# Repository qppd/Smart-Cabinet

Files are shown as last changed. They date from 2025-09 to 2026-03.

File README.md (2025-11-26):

<div align="center">

# Smart Cabinet System






**An advanced IoT-enabled secure storage solution with fingerprint authentication, automated mechanisms, and intelligent monitoring.**

*Engineered by [QPPD](https://github.com/qppd) for smart access control and automated storage management.*

</div>

---

## 🎉 Project Status: COMPLETE

**The Smart Cabinet System is now fully finished and operational!** ✅

All core features have been implemented, tested, and validated:
- ✅ **Fingerprint Authentication**: Reliable biometric access with proper ID management
- ✅ **Motor Control System**: Precise stepper motor operations with watchdog protection
- ✅ **ESP-NOW Communication**: Stable peer-to-peer communication between host and client
- ✅ **Safety Systems**: Emergency stops, limit switches, and fail-safe mechanisms
- ✅ **3D Mechanical Design**: Complete assembly with custom mounting brackets and enclosures
- ✅ **User Interface**: LCD display, buzzer feedback, and tactile controls
- ✅ **Testing Suite**: Comprehensive validation commands for all subsystems

The system is ready for production deployment and real-world use.

---

## Recent Changes (v3.0)

### December 2025 Update - PROJECT COMPLETE
- **Full System Completion**: All features implemented and tested successfully
- **3D Model Documentation**: Added full assembly visualizations and component details
- **Production Ready**: System validated for real-world deployment
- **Documentation Enhancement**: Comprehensive README with visual guides and setup instructions
- **Code Optimization**: Final fixes for motor control, fingerprint management, and safety systems

### November 2025 Update
- **Motor Direction Inversion**: Corrected cabinet operation - fingerprint authentication now opens door (CCW), test_motor_limit closes door (CW)
- **Enhanced Testing Suite**: Added comprehensive door testing commands with proper stop conditions
- **test_close_door**: New command to close door until limit switch is pressed (CW direction)
- **test_open_door**: New command to open door for exact CLIENT_DOOR_OPEN_STEPS (CCW direction)
- **Updated State Machine**: Fixed executeUnlock(), handleOpeningState(), and handleClosingState() for correct motor directions

### October 2025 Update
- ESP-NOW Communication - Replaced WebSocket with ESP-NOW for reliable host-client communication
- Fingerprint Enrollment System - One-button enrollment via tactile button on GPIO 23
- Fixed Authentication Flow - Resolved double-read issue for reliable fingerprint matching
- Improved LCD Display - Eliminated flickering with optimized refresh logic
- Enhanced Buzzer System - Non-blocking PWM-based buzzer with proper timing
- NTP Time Synchronization - Internet-based time display (GMT+8)
- Fingerprint Management - Delete fingerprints and empty database features
- WiFi Integration - Automatic WiFi connection for NTP synchronization
- TactileButton Class - Debounced button handler with press/hold detection
- ESP32 Core 3.1.2 Support - Updated ESP-NOW callbacks for latest Arduino core

---

## Table of Contents

- [Overview](#overview)
- [Key Features](#key-features)
- [System Architecture](#system-architecture)
- [Hardware Requirements](#hardware-requirements)
- [Wiring Diagram](#wiring-diagram)
- [Software Dependencies](#software-dependencies)
- [Installation & Setup](#installation--setup)
- [Configuration](#configuration)
- [Operation Guide](#operation-guide)
- [API & Communication](#api--communication)
- [Testing & Validation](#testing--validation)
- [Troubleshooting](#troubleshooting)
- [Project Structure](#project-structure)
- [Future Enhancements](#future-enhancements)
- [Contributing](#contributing)
- [Support & Contact](#support--contact)
- [License](#license)

---

## Overview

The **Smart Cabinet System** is a sophisticated IoT-enabled secure storage solution designed for environments requiring controlled access and intelligent automation. This dual-controller architecture provides robust security, and seamless user interaction through biometric authentication and automated mechanical operations.

### Project Goals
- **Security**: Multi-layered access control with biometric authentication
- **Automation**: Intelligent operation with minimal user intervention  
- **Safety**: Comprehensive emergency systems and fail-safes
- **Scalability**: Modular design for easy expansion and customization
- **Reliability**: Robust error handling and system recovery

---

## Key Features

### Advanced Security
- **Biometric Authentication**: AS608 fingerprint sensor with 50+ user capacity
- **One-Touch Enrollment**: Simple button-press enrollment system (GPIO 23)
- **Reliable Matching**: Fixed authentication flow for consistent fingerprint recognition
- **Multi-layer Locking**: Electronic solenoid + mechanical stepper motor locks
- **Access Logging**: Real-time authentication tracking and user management
- **Emergency Override**: Manual unlock procedures for critical situations

### Intelligent Automation
- **Smart Motion Detection**: PIR sensor with adaptive sensitivity
- **Auto-Close System**: Configurable timeout (default: 60 seconds)
- **State Management**: Advanced finite state machine for reliable operation

### Safety Systems
- **Emergency Stop**: Immediate motor shutdown via limit switches
- **Position Monitoring**: Reed switch for precise door state detection
- **Fail-Safe Design**: Secure lock state during power failures

### Connectivity
- **ESP-NOW Communication**: Ultra-low latency peer-to-peer communication between controllers
- **WiFi Integration**: Network connectivity for NTP time synchronization

### User Experience
- **Visual Feedback**: 20x4 I2C LCD with flicker-free status information
- **Audio Alerts**: Multi-tone buzzer notifications
- **LED Illumination**: Automatic interior lighting control
- **Time Display**: NTP-synchronized real-time clock with timezone support
- **Simple Enrollment**: One-button fingerprint registration process

---

## System Architecture

### Distributed Controller Design

```mermaid
graph TB
    subgraph "HOST CONTROLLER (Authentication & Logic)"
        A[ESP32 Host] --> B[Fingerprint Sensor AS608]
        A --> C[20x4 I2C LCD Display]
        A --> D[NTP Time Sync]
        A --> E[Buzzer Audio Feedback]
        A --> F[ESP-NOW Host]
        A --> G[Enrollment Button GPIO 23]
    end
    
    subgraph "CLIENT CONTROLLER (Physical Operations)"
        H[ESP32 Client] --> I[PIR Motion Sensor]
        H --> J[TB6600 Motor Driver 1<br/>Door Mechanism]
        H --> K[TB6600 Motor Driver 2<br/>Lock Mechanism]
        H --> L[4-Channel Relay Board]
        H --> M[Safety Switches]
        H --> N[Reed Switch]
        H --> O[ESP-NOW Client]
    end
    
    subgraph "Physical Hardware"
        P[NEMA 17 Stepper Motors]
        Q[Solenoid Lock]
        R[LED Strip Lighting]
        S[Limit Switches]
    end
    
    F <==>|ESP-NOW Protocol| O
    J --> P
    K --> P
    L --> Q
    L --> R
    M --> S
```

### Control Flow Architecture

```mermaid
stateDiagram-v2
    [*] --> LOCKED
    LOCKED --> AUTHENTICATING : User Present
    AUTHENTICATING --> OPENING : Valid Fingerprint
    AUTHENTICATING --> LOCKED : Invalid/Timeout
    OPENING --> OPEN : Door Fully Open
    OPEN --> CLOSING : Motion Timeout
    OPEN --> CLOSING : Manual Close
    CLOSING --> LOCKED : Door Secured
    
    OPENING --> ERROR : Motor Timeout
    CLOSING --> ERROR : Motor Timeout
    ERROR --> LOCKED : System Reset
```

---

## Hardware Requirements

### Microcontrollers
| Component | Specification | Quantity | Purpose |
|---|---|---|---|
| **ESP32 DevKit** | 240MHz, 4MB Flash, WiFi/BT | 2 | Host & Client Controllers |

### Sensors & Input Devices
| Component | Model/Type | Interface | Function |
|---|---|---|---|
| **Fingerprint Sensor** | AS608/R307 | UART (Serial2) | Biometric Authentication |
| **Enrollment Button** | Tactile Push Button | Digital GPIO 23 | Fingerprint Enrollment Trigger |
| **PIR Motion Sensor** | HC-SR501 | Digital GPIO | User Presence Detection |
| **Reed Switch** | Magnetic Contact | Digital GPIO | Door Position Sensing |
| **Limit Switches** | Mechanical NO/NC | Digital GPIO | Motor Safety Limits |

### Actuators & Motor Control
| Component | Specification | Quantity | Application |
|---|---|---|---|
| **Stepper Motors** | NEMA 17, 1.8°/step | 2 | Door & Lock Mechanisms |
| **TB6600 Drivers** | 4A, 9-42V Input | 2 | Stepper Motor Control |
| **Solenoid Lock** | 12V, Fail-Secure | 1 | Primary Locking Mechanism |
| **4-Channel Relay** | 5V Logic, 10A Contact | 1 | Power Switching Control |

### Display & Feedback
| Component | Specification | Interface | Purpose |
|---|---|---|---|
| **LCD Display** | 20x4 Character, I2C | I2C Bus | System Status & Messages |
| **Buzzer** | Piezo, 2-5V | PWM GPIO | Audio Feedback |
| **LED Strip** | 12V, Addressable | Relay Control | Interior Illumination |

### Power Requirements
| System Component | Voltage | Current | Notes |
|---|---|---|---|
| **ESP32 Controllers** | 5V | 500mA each | Via USB or external supply |
| **Logic Components** | 3.3V/5V | 200mA total | From ESP32 regulation |
| **Stepper Motors** | 12-24V | 2-4A peak | Separate high-power supply |
| **Solenoid & LEDs** | 12V | 1A continuous | Shared with motor supply |

---

### 3D Printed Enclosures

Custom-designed 3D printable components for professional installation and sensor protection.

#### Fingerprint Scanner Components
| Component | File Format | Purpose | Print Time | Material |
|---|---|---|---|---|
| **Scanner Case** | STL + G-code | AS608/R307 protective enclosure | 2-3 hours | PLA/PETG |
| **Mounting Bracket** | STL + G-code | Secure cabinet attachment | 1-2 hours | PLA/PETG |

**Features:**
- Snap-fit design for easy sensor installation
- Integrated wire management channels
- Professional appearance for user-facing installation
- Pre-sliced G-code available for Creality Ender 3 V3 SE

**Printing Specifications:**
- **Layer Height:** 0.2mm recommended
- **Infill Density:** 20-30% for optimal strength-to-weight ratio
- **Support Material:** Required for overhangs (auto-generated in slicer)
- **Nozzle Temperature:** PLA: 200-210°C, PETG: 230-250°C
- **Bed Temperature:** PLA: 60°C, PETG: 80°C

**Files Location:** All STL and G-code files available in [`model/`](https://github.com/qppd/Smart-Cabinet/tree/main/model) directory

---

### 3D Model Visualizations

Complete assembly views of the Smart Cabinet mechanical system showcasing all custom-designed components.

<div align="center">

#### Full Assembly View (Wireframe)
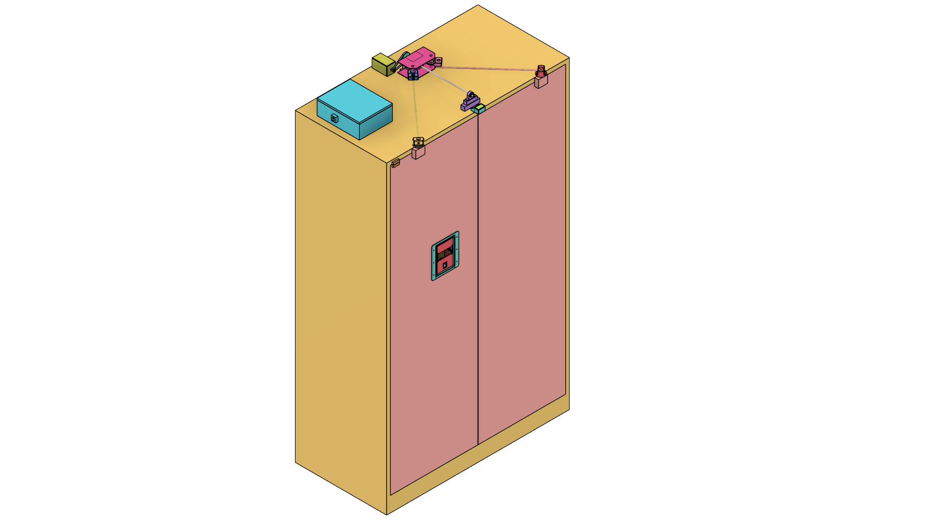
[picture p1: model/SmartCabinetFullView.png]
Smart Cabinet Full View

*Complete mechanical assembly showing internal component placement and motor mounting systems*

#### Full Assembly View (Rendered)
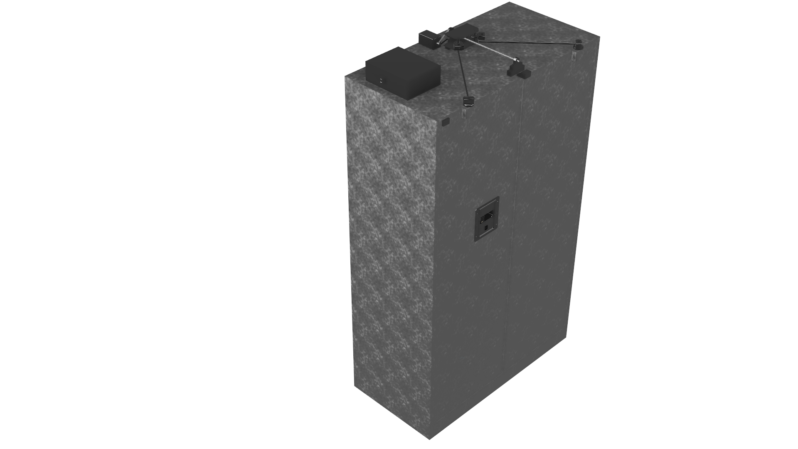
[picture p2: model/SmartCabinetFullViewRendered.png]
Smart Cabinet Rendered View

*Photorealistic render of the assembled Smart Cabinet with all mounting brackets and hardware*

</div>

**Assembly Components Include:**
- Stepper motor mounting brackets with integrated bearing supports
- Door puller mechanism with linear actuator mount
- Limit switch mounting system with protective covers
- Motion sensor bracket for optimal detection coverage
- Fingerprint scanner enclosure with mounting plate
- Cable management channels and wire routing guides

**Design Features:**
- Modular component system for easy maintenance and upgrades
- Integrated mounting points for all electronic components
- Optimized clearances for smooth mechanical operation
- Professional appearance with clean, modern aesthetics
- All components designed for standard FDM 3D printing

**Individual Component Views:** Detailed images of each mounting bracket and enclosure available in the [`model/`](https://github.com/qppd/Smart-Cabinet/tree/main/model) directory.

---

### Component Procurement Guide

#### **Microcontrollers & Development Boards**
| Component | Specifications | Supplier | Approximate Cost | Notes |
|---|---|---|---|---|
| **ESP32 DevKit V1** | ESP32-WROOM-32, 38-pin | Amazon, AliExpress | $8-15 | Ensure CH340 USB chip |
| **ESP32 DevKit V4** | ESP32-WROOM-32D, 38-pin | Espressif, DigiKey | $12-20 | Official version |

#### **Sensors & Input Devices**
| Component | Model | Specifications | Supplier | Cost |
|---|---|---|---|---|
| **Fingerprint Sensor** | AS608 / R307 | UART, 50 templates | Amazon, AliExpress | $15-25 |
| **PIR Motion Sensor** | HC-SR501 | 3-7m range, 3.3V logic | Amazon, SparkFun | $3-8 |
| **Reed Switch** | MC-38 | Magnetic, NO contact | Amazon, AliExpress | $2-5 |
| **Limit Switches** | KW12-3 | Microswitch, NO/NC | Amazon, McMaster | $3-8 each |
| **Tactile Button** | 12mm | 4-pin, momentary | Amazon, Adafruit | $1-3 |

#### **Motor Control Components**
| Component | Model | Specifications | Supplier | Cost |
|---|---|---|---|---|
| **NEMA 17 Motors** | 17HS4401 | 1.8°, 1.7A, 4-wire | Amazon, StepperOnline | $15-25 each |
| **TB6600 Drivers** | TB6600HG | 4A, 9-42V, 32μstepping | Amazon, AliExpress | $12-20 each |
| **4-Channel Relay** | SRD-05VDC-SL-C | 5V coil, 10A contact | Amazon, AliExpress | $8-15 |
| **Solenoid Lock** | 12V Electric Lock | Fail-secure, 12V DC | Amazon, Security stores | $20-40 |

#### **Display & Interface**
| Component | Model | Specifications | Supplier | Cost |
|---|---|---|---|---|
| **I2C LCD** | 2004A + I2C Module | 20x4, HD44780, 0x27 | Amazon, AliExpress | $8-15 |
| **DS1302 RTC** | DS1302 Module | Real-time clock, battery | Amazon, AliExpress | $3-8 |
| **Piezo Buzzer** | Active/Passive | 3-5V, PCB mount | Amazon, DigiKey | $2-5 |

#### **Power Supply Components**
| Component | Specifications | Supplier | Cost | Notes |
|---|---|---|---|---|
| **Switching PSU** | 12V 5A (60W) | Amazon, Mean Well | $15-30 | Choose reputable brand |
| **Buck Converter** | LM2596 12V→5V 3A | Amazon, AliExpress | $3-8 | Adjustable output |
| **Power Jack** | 5.5×2.1mm DC Jack | Amazon, DigiKey | $2-5 | Panel mount |

#### **Wiring & Connectors**
| Item | Specifications | Supplier | Cost | Quantity |
|---|---|---|---|---|
| **Hookup Wire** | 22AWG stranded | Amazon, McMaster | $10-20 | 10m spools |
| **Power Wire** | 16AWG stranded | Amazon, McMaster | $15-25 | 5m spool |
| **Dupont Connectors** | 2.54mm pitch | Amazon, AliExpress | $5-10 | 100pc kit |
| **Terminal Blocks** | 3.5mm pitch | Amazon, Phoenix | $10-20 | Various sizes |
| **Heat Shrink** | Assorted sizes | Amazon, 3M | $8-15 | Multi-size kit |

### Total Estimated Cost
| Category | Cost Range |
|---|---|
| **Controllers & Sensors** | $60-120 |
| **Motor System** | $80-150 |
| **Power & Wiring** | $40-80 |
| **Enclosure & Mechanical** | $50-150 |
| **Total Project Cost** | **$230-500** |

*Costs vary by supplier, quantity, and quality. Budget for 20% contingency.*

---

## Wiring Diagram

### System Wiring Overview

#### HOST Controller Wiring

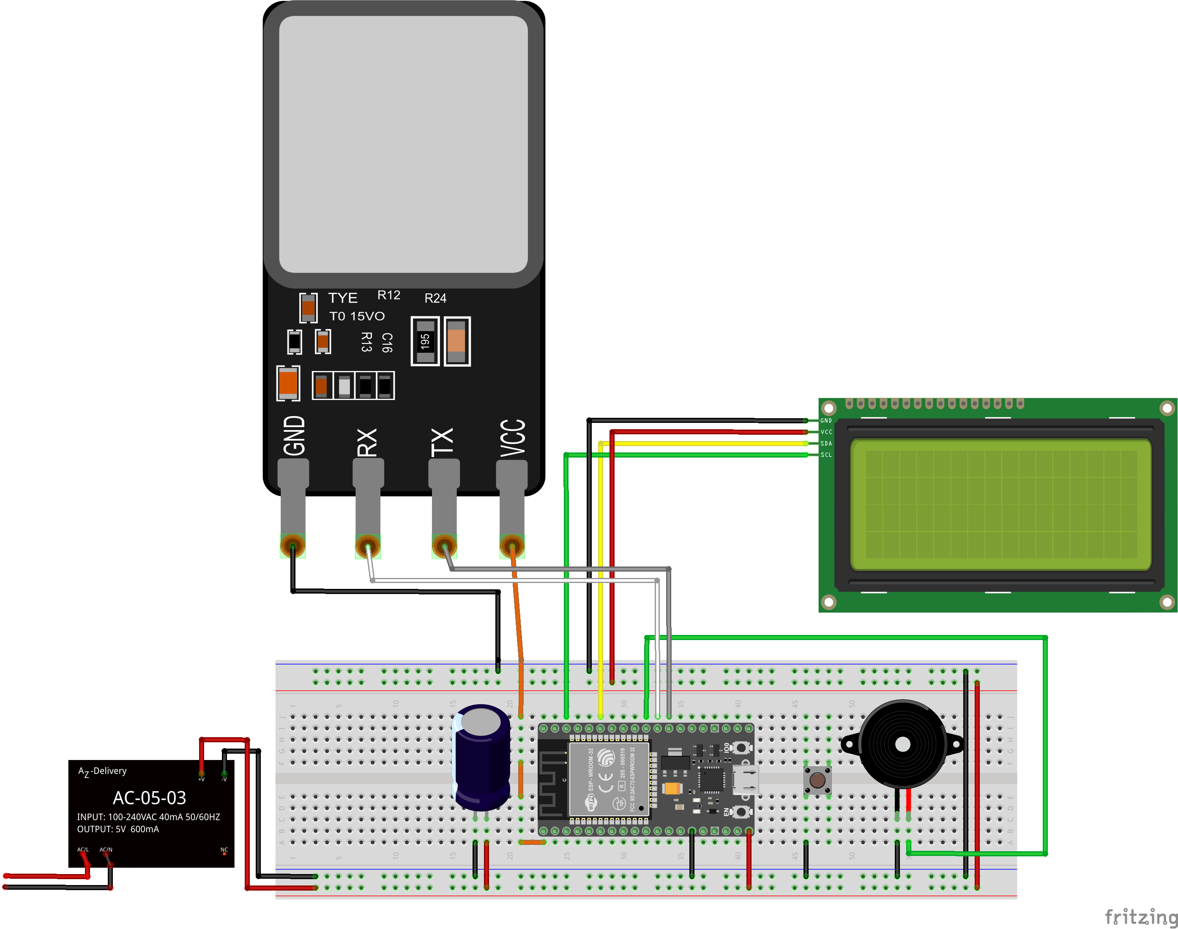
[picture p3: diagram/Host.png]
Smart Cabinet Host Wiring Diagram


*HOST controller wiring schematic showing authentication and user interface connections*

#### CLIENT Controller Wiring

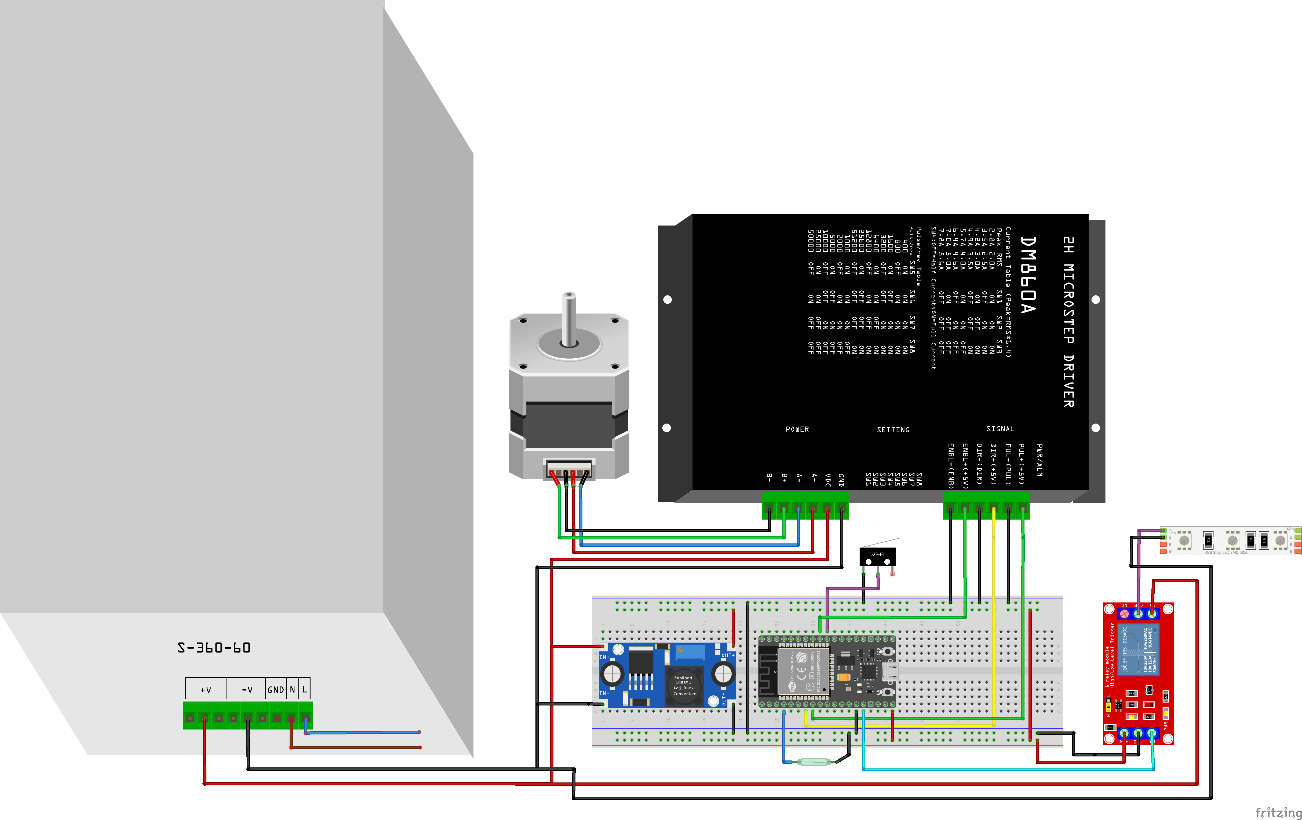
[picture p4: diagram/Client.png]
Smart Cabinet Client Wiring Diagram


*CLIENT controller wiring schematic showing motor control and safety system connections*

### Dual-Controller Architecture

The Smart Cabinet system uses a distributed controller architecture with two ESP32 microcontrollers:

- **HOST Controller (ESP32 #1)**: Handles authentication, user interface, and system coordination
- **CLIENT Controller (ESP32 #2)**: Manages mechanical operations, motor control, and safety systems

Communication between controllers uses **ESP-NOW protocol** for ultra-low latency and reliable peer-to-peer communication.

---

### HOST Controller Connections (ESP32 #1)

#### Display & User Interface
| Component | ESP32 Pin | Wire Color | Connection Details | Voltage |
|---|---|---|---|---|
| **20x4 I2C LCD** | SDA: 21 | Blue | I2C Data Line | 5V |
| | SCL: 22 | Yellow | I2C Clock Line | 5V |
| | VCC | Red | Power Supply | 5V |
| | GND | Black | Common Ground | GND |
| | **I2C Address: 0x27** | | *Use I2C scanner if different* | |

#### Authentication System
| Component | ESP32 Pin | Wire Color | Connection Details | Protocol |
|---|---|---|---|---|
| **AS608 Fingerprint Sensor** | TX2: 17 | Green | UART Transmit | Serial2 |
| | RX2: 16 | White | UART Receive | Serial2 |
| | VCC | Red | Power Supply | 3.3V |
| | GND | Black | Common Ground | GND |
| **Enrollment Button** | GPIO 23 | Orange | Digital Input | Pull-up |
| | GND | Black | Button Common | GND |

#### Real-Time Clock Module
| Component | ESP32 Pin | Wire Color | Connection Details | Interface |
|---|---|---|---|---|
| **DS1302 RTC** | CE: 0 | Purple | Chip Enable/Reset | Digital |
| | CLK: 19 | Gray | Clock Signal | Digital |
| | DAT: 18 | Brown | Data I/O | Digital |
| | VCC | Red | Power Supply | 5V |
| | GND | Black | Common Ground | GND |

#### Audio Feedback
| Component | ESP32 Pin | Wire Color | Connection Details | Control |
|---|---|---|---|---|
| **Piezo Buzzer** | GPIO 5 | Pink | PWM Signal | LEDC Ch.0 |
| | GND | Black | Common Ground | GND |

#### Power & Communication
| Connection | ESP32 Pin | Wire Color | Specification | Notes |
|---|---|---|---|---|
| **Power Input** | VIN | Red | 5V DC Input | From buck converter |
| | GND | Black | Common Ground | Shared with all components |
| **ESP-NOW** | Built-in WiFi | | 2.4GHz Radio | Peer-to-peer with CLIENT |

---

### CLIENT Controller Connections (ESP32 #2)

#### Motion Detection
| Component | ESP32 Pin | Wire Color | Connection Details | Type |
|---|---|---|---|---|
| **PIR Motion Sensor** | GPIO 34 | Orange | Digital Input | Input-only pin |
| | VCC | Red | Power Supply | 5V |
| | GND | Black | Common Ground | GND |

#### Motor Control System

**TB6600 Stepper Driver #1 (Door/Drawer Motor):**
| Function | ESP32 Pin | TB6600 Pin | Wire Color | Purpose |
|---|---|---|---|---|
| **Direction** | GPIO 2 | DIR+ | Blue | Rotation direction |
| **Step Pulse** | GPIO 4 | PUL+ | Green | Step commands |
| **Enable** | GPIO 15 | ENA+ | White | Driver enable (LOW=active) |
| **Common** | GND | DIR-, PUL-, ENA- | Black | Signal ground |

**TB6600 Stepper Driver #2 (Lock Mechanism Motor):**
| Function | ESP32 Pin | TB6600 Pin | Wire Color | Purpose |
|---|---|---|---|---|
| **Direction** | GPIO 32 | DIR+ | Yellow | Rotation direction |
| **Step Pulse** | GPIO 33 | PUL+ | Orange | Step commands |
| **Enable** | GPIO 5 | ENA+ | Purple | Driver enable (LOW=active) |
| **Common** | GND | DIR-, PUL-, ENA- | Black | Signal ground |

**TB6600 Power Connections:**
| Terminal | Connection | Wire Gauge | Voltage | Current |
|---|---|---|---|---|
| **VCC/VDD** | +12V Power | 16 AWG | 12V DC | 4A Max |
| **GND** | Power Ground | 16 AWG | GND | Return |
| **A+, A-** | Motor Phase A | 18 AWG | Motor | 2A |
| **B+, B-** | Motor Phase B | 18 AWG | Motor | 2A |

#### Relay Control System
| Relay | ESP32 Pin | Load Connection | Wire Color | Purpose | Max Load |
|---|---|---|---|---|---|
| **Relay 1** | GPIO 12 | Solenoid Lock | Red | Primary lock mechanism | 10A @ 250V |
| **Relay 2** | GPIO 13 | LED Strip | Blue | Interior illumination | 10A @ 250V |
| **Relay 3** | GPIO 14 | Auxiliary 1 | Green | Future expansion | 10A @ 250V |
| **Relay 4** | GPIO 27 | Auxiliary 2 | Yellow | Future expansion | 10A @ 250V |

**Relay Module Power:**
| Terminal | Connection | Wire Color | Voltage |
|---|---|---|---|
| **VCC** | +5V | Red | 5V DC |
| **GND** | Ground | Black | GND |
| **JD-VCC** | +5V | Red | Optocoupler power |

#### Safety & Sensors
| Component | ESP32 Pin | Wire Color | Connection Type | Function |
|---|---|---|---|---|
| **Limit Switch MIN** | GPIO 35 | Brown | NO Contact | Minimum position detect |
| **Limit Switch MAX** | GPIO 36 | Orange | NO Contact | Maximum position detect |
| **Reed Switch** | GPIO 39 | Purple | Magnetic Contact | Door closed detection |
| **Common Ground** | GND | Black | Switch Common | All sensor returns |

#### Power & Communication
| Connection | ESP32 Pin | Wire Color | Specification | Notes |
|---|---|---|---|---|
| **Power Input** | VIN | Red | 5V DC Input | From buck converter |
| | GND | Black | Common Ground | Shared with all components |
| **ESP-NOW** | Built-in WiFi | | 2.4GHz Radio | Peer-to-peer with HOST |

---

### Power Distribution System

```
 Main Power Supply (12V 5A Switching PSU)
├──  TB6600 Motor Driver #1 (12V 2A) ──→  NEMA 17 Door Motor
├──  TB6600 Motor Driver #2 (12V 2A) ──→  NEMA 17 Lock Motor  
├──  Solenoid Lock (12V 1A) ──→ via Relay 1
├──  LED Strip (12V 1A) ──→ via Relay 2
└──  Buck Converter (LM2596) (12V → 5V 3A)
    ├──  ESP32 Host Controller (5V 500mA)
    ├──  ESP32 Client Controller (5V 500mA)
    ├──  20x4 I2C LCD Display (5V 200mA)
    ├──  AS608 Fingerprint Sensor (3.3V 100mA)
    ├──  PIR Motion Sensor (5V 50mA)
    ├──  DS1302 RTC Module (5V 10mA)
    ├──  Piezo Buzzer (5V 20mA)
    ├──  4-Channel Relay Module (5V 150mA)
    └──  Safety Switches & Sensors (5V 50mA)
```

### Connector & Terminal Specifications

#### Recommended Connectors
| Connection Type | Connector | Wire Gauge | Rating |
|---|---|---|---|
| **Power (12V)** | Terminal Block | 14-16 AWG | 15A |
| **Motor Connections** | Terminal Block | 16-18 AWG | 5A |
| **Signal Wires** | Dupont Connectors | 22-24 AWG | 1A |
| **Sensor Cables** | JST Connectors | 24-26 AWG | 500mA |

#### Wire Color Standards
| Function | Color | Purpose |
|---|---|---|
| **Power (+)** | Red | Positive voltage |
| **Ground (-)** | Black | Ground/negative |
| **Data/Signal** | Various | Digital I/O |
| **I2C SDA** | Blue | I2C data |
| **I2C SCL** | Yellow | I2C clock |
| **UART TX** | Green | Serial transmit |
| **UART RX** | White | Serial receive |

### Assembly Notes

#### Critical Safety Requirements
1. **Isolation**: Keep high-voltage (12V motor) and low-voltage (5V logic) circuits separated
2. **Grounding**: Use common ground point to prevent ground loops
3. **Fusing**: Install appropriate fuses on 12V power lines
4. **Strain Relief**: Secure all cables to prevent disconnection during operation

#### Testing Checklist
- [ ] Verify all power supply voltages before connecting ESP32 controllers
- [ ] Test continuity of all signal connections
- [ ] Confirm proper motor driver configuration (current limiting)
- [ ] Validate safety switch operation (emergency stops)
- [ ] Check ESP-NOW communication range and reliability

### Advanced Wiring Considerations

#### Electromagnetic Interference (EMI) Mitigation

**Motor Noise Suppression:**
```
┌─ Stepper Motor Cable (Shielded)
├─ Ferrite Core (Split-bead, 10-30MHz)
├─ Twisted Pair Wiring (A+/A-, B+/B-)
└─ Shield Connection to Motor Frame Ground

TB6600 Layout:
- Separate analog/digital grounds
- Place 0.1μF ceramic caps near logic pins
- Use 1000μF electrolytic on motor supply
- Keep switching circuits away from ESP32
```

**Signal Integrity Protection:**
```
Critical Signals (I2C, UART, SPI):
├─ Use twisted pair or shielded cable <30cm
├─ Add series resistors (47Ω) for signal damping
├─ Ground shield at one end only (avoid ground loops)
└─ Route away from switching power circuits

Digital Input Protection:
├─ 10kΩ pull-up resistors on all inputs
├─ 100pF ceramic caps for debouncing
├─ TVS diodes for ESD protection (optional)
└─ Optical isolation for noisy environments
```

#### Professional Installation Practices

**Cable Management:**
- Use cable trays or conduit for organized routing
- Maintain 6" separation between power and signal cables
- Label all cables with wire markers or heat shrink labels
- Create service loops for future maintenance access

**Grounding Strategy:**
- Establish single-point ground (star configuration)
- Use heavy gauge wire (12-14 AWG) for ground bus
- Connect all metal enclosures to safety ground
- Install ground fault circuit breaker for AC power

**Environmental Considerations:**
- IP65 rated enclosures for humid environments
- Operating temperature: -10°C to +50°C
- Ventilation for heat dissipation from motor drivers
- Vibration dampening for stepper motor mounting

#### Safety & Code Compliance

**Electrical Safety:**
- Install 5A slow-blow fuse on 12V supply
- Use UL-listed power supplies and enclosures
- Implement emergency stop (E-stop) button
- Ground fault protection for wet locations

**Fire Safety:**
- Use flame-retardant cable jacket materials
- Install thermal protection on motor drivers
- Smoke detection in enclosed installations
- Regular inspection of electrical connections

#### Maintenance & Serviceability

**Test Points & Diagnostics:**
- Install LED indicators for power rails
- Add test points for critical signals
- Include voltage monitoring in software
- Document all modifications and settings

**Spare Parts & Backup:**
- Keep spare ESP32 controllers programmed
- Stock critical sensors (fingerprint, PIR)
- Backup configuration settings to SD card
- Create wiring diagram updates for changes**

### Installation Checklist

#### Pre-Installation Verification
```bash
□ All components tested individually
□ Power supply load tested at full current
□ Cable continuity verified with multimeter
□ Insulation resistance >1MΩ measured
□ Grounding system continuity confirmed
```

#### Installation Steps
```bash
□ Mount ESP32 controllers in protective enclosures
□ Install power distribution (fused and switched)
□ Route and secure all signal cables
□ Connect motor drivers and test without motors
□ Install and calibrate all sensors
□ Perform full system integration test
```

#### Commissioning Tests
```bash
□ Power-on sequence verification
□ ESP-NOW communication test
□ Motor movement and limit switch operation
□ Fingerprint enrollment and authentication
□ Emergency stop and safety system test
□ Long-term reliability test (24-48 hours)
```

---

## Software Dependencies

### Required Arduino Libraries

| Library | Version | Repository | Purpose |
|---|---|---|---|
| **LiquidCrystal_I2C** | ≥1.1.2 | [johnrickman/LiquidCrystal_I2C](https://github.com/johnrickman/LiquidCrystal_I2C) | I2C LCD Control |
| **Adafruit Fingerprint** | ≥2.1.0 | [adafruit/Adafruit-Fingerprint-Sensor-Library](https://github.com/adafruit/Adafruit-Fingerprint-Sensor-Library) | AS608 Communication |
| **RTClib** | ≥2.1.1 | [adafruit/RTClib](https://github.com/adafruit/RTClib) | DS1302 RTC Interface |
| **ArduinoWebsockets** | ≥0.5.3 | [gilmaimon/ArduinoWebsockets](https://github.com/gilmaimon/ArduinoWebsockets) | WebSocket Communication |
| **ArduinoJson** | ≥6.21.2 | [bblanchon/ArduinoJson](https://github.com/bblanchon/ArduinoJson) | JSON Message Processing |
| **WiFi** | Built-in | ESP32 Core | Network Connectivity |

### Development Environment

| Tool | Version | Download Link |
|---|---|---|
| **Arduino IDE** | ≥2.0.0 | [arduino.cc/software](https://www.arduino.cc/en/software) |
| **ESP32 Board Package** | ≥2.0.9 | [Espressif Arduino Core](https://github.com/espressif/arduino-esp32) |
| **VS Code** (Optional) | Latest | [PlatformIO Extension](https://platformio.org/platformio-ide) |

### Library Installation

**Via Arduino IDE Library Manager:**
```cpp
// Search and install each library:
// 1. LiquidCrystal_I2C by Frank de Brabander
// 2. Adafruit Fingerprint Sensor Library  
// 3. RTClib by Adafruit
// 4. ArduinoWebsockets by Gil Maimon
// 5. ArduinoJson by Benoit Blanchon
```

**Via PlatformIO (platformio.ini):**
```ini
[env:esp32dev]
platform = espressif32
board = esp32dev
framework = arduino
lib_deps = 
    johnrickman/LiquidCrystal_I2C@^1.1.2
    adafruit/Adafruit Fingerprint Sensor Library@^2.1.0
    adafruit/RTClib@^2.1.1
    gilmaimon/ArduinoWebsockets@^0.5.3
    bblanchon/ArduinoJson@^6.21.2
```

---

## Installation & Setup

### Hardware Assembly

#### 1. 3D Print Components (If Using Custom Enclosures)

**Print the Scanner Components:**
```bash
Option A: Use Pre-sliced G-code (Creality Ender 3 V3 SE)
  - Load CE3V3SE_Cabinet_Scanner_Case.gcode
  - Load CE3V3SE_Cabinet_Scanner_Case_Mount.gcode
  - Print with PLA or PETG filament

Option B: Slice STL Files (Any 3D Printer)
  - Import Cabinet_Scanner_Case.stl into your slicer
  - Import Cabinet_Scanner_Case_Mount.stl into your slicer
  - Configure settings: 0.2mm layer height, 20-30% infill
  - Generate and print G-code
```

**Assembly Instructions:**
- Allow printed parts to cool completely before handling
- Test-fit AS608/R307 sensor in scanner case before final assembly
- Clean any support material or stringing from prints
- Optional: Sand and paint for professional finish

#### 2. Mount Controllers and Sensors

1. **Install Fingerprint Scanner**: 
   - Insert AS608 sensor into printed scanner case
   - Secure with snap-fit mechanism or adhesive
   - Attach mounting bracket to cabinet using screws
   - Position at comfortable height for user access (typically 120-150cm)

2. **Mount ESP32 Controllers**: Secure both boards in protective enclosures or chassis

3. **Install Mechanical Components**:
   - Mount stepper motors for door and lock mechanisms
   - Position PIR motion sensor for optimal coverage
   - Install limit switches at mechanical endpoints

#### 3. Power and Wiring

1. **Connect Power**: Wire 12V supply to motor drivers and buck converter  
2. **Wire Sensors**: Follow pin configuration tables for all connections
3. **Cable Management**: Use wire channels in 3D printed parts for clean routing
4. **Test Connections**: Verify continuity and proper voltage levels

### Software Installation

**Clone Repository:**
```bash
git clone https://github.com/qppd/Smart-Cabinet.git
cd Smart-Cabinet
```

**Install Libraries:**
```bash
# If using Arduino IDE:
# 1. Open Library Manager (Ctrl+Shift+I)
# 2. Search and install required libraries listed above

# If using PlatformIO:
pio lib install
```

### Upload Firmware

**HOST Controller (Authentication Unit):**
```bash
# Navigate to host directory
cd source/host/SmartCabinet/

# Configure pins.h with your hardware setup
# Upload via Arduino IDE or PlatformIO to ESP32 #1
```

**CLIENT Controller (Mechanical Unit):**
```bash
# Navigate to client directory  
cd source/client/SmartCabinet/

# Configure client_pins.h with your hardware setup
# Upload via Arduino IDE or PlatformIO to ESP32 #2
```

### Initial System Verification

```bash
# Open Serial Monitor for both controllers
# Verify initialization messages:
# - WiFi connection established
# - All sensors responding
# - WebSocket connection active
# - Motor drivers enabled
```

---

## Configuration

### Network Configuration

**HOST Controller (`source/host/SmartCabinet/pins.h`):**
```cpp
// WiFi Network Settings
static const char* HOST_WIFI_SSID = "YourNetworkName";
static const char* HOST_WIFI_PASSWORD = "YourNetworkPassword";
static const uint16_t HOST_WEBSOCKET_PORT = 81;

// System Timing (milliseconds)
static const unsigned long HOST_DISPLAY_UPDATE_INTERVAL = 1000;
static const unsigned long HOST_FINGERPRINT_CHECK_INTERVAL = 500;
static const unsigned long HOST_STATUS_BROADCAST_INTERVAL = 5000;

// Security Settings
static const uint8_t MAX_FINGERPRINT_ATTEMPTS = 3;
static const unsigned long LOCKOUT_DURATION = 30000; // 30 seconds
static const uint8_t MAX_ENROLLED_FINGERPRINTS = 50;
```

**CLIENT Controller (`source/client/SmartCabinet/client_pins.h`):**
```cpp
// Network Connection
static const char* CLIENT_WIFI_SSID = "YourNetworkName";
static const char* CLIENT_WIFI_PASSWORD = "YourNetworkPassword";
static const char* CLIENT_WEBSOCKET_HOST = "192.168.1.100"; // HOST IP
static const uint16_t CLIENT_WEBSOCKET_PORT = 81;

// Motion & Timing Settings
static const unsigned long CLIENT_MOTION_TIMEOUT = 60000;      // 60 sec auto-close
static const unsigned long CLIENT_MOTOR_TIMEOUT = 30000;       // 30 sec motor limit
static const unsigned long CLIENT_WEBSOCKET_RETRY = 5000;      // 5 sec reconnect

// Motor Configuration (steps)
static const unsigned long CLIENT_DOOR_OPEN_STEPS = 2000;      // Full door travel
static const unsigned long CLIENT_DOOR_CLOSE_STEPS = 2000;
static const unsigned long CLIENT_LOCK_ENGAGE_STEPS = 400;     // Lock mechanism
static const unsigned long CLIENT_LOCK_RELEASE_STEPS = 400;

// Motor Speed (microseconds)
static const unsigned int CLIENT_MOTOR_PULSE_US = 100;         // Pulse width
static const unsigned int CLIENT_MOTOR_GAP_US = 800;           // Speed control
```

### Hardware Calibration

**Motor Step Calculation:**
```cpp
// Formula: Steps = (Degrees / Motor_Step_Angle) * Microstep_Setting
// Example: (90° / 1.8°) * 16 = 800 steps for 90° rotation

// Measure actual travel distances and adjust:
CLIENT_DOOR_OPEN_STEPS = measured_distance_mm * steps_per_mm;
CLIENT_LOCK_ENGAGE_STEPS = lock_rotation_degrees * steps_per_degree;
```

**Sensor Calibration:**
```cpp
// PIR Motion Sensor (adjust via potentiometers):
// - Sensitivity: Set to avoid false triggers
// - Time Delay: Minimum 3 seconds for stable operation

// Reed Switch: Test with magnet at various distances
// Optimal gap: 5-10mm for reliable switching
```

---

##  Operation Guide

### User Authentication Process

1. **Approach Cabinet**: Motion sensor detects user presence
2. **Fingerprint Scan**: Place enrolled finger on AS608 sensor
3. **Processing**: Host controller verifies biometric data (single-pass authentication)
4. **Access Grant**: Valid fingerprint triggers unlock sequence
5. **Automatic Opening**: Client executes door opening mechanism via ESP-NOW

**Authentication Flow:**
-  **Success**: LCD shows "Access Granted!" + ascending beeps + door unlocks
-  **Denied**: LCD shows "Access Denied!" + error beeps (3 short beeps)
- ⏸ **No Finger**: Silent operation (no spam messages)

### Fingerprint Enrollment

**Quick Enrollment Process:**

1. **Press Enrollment Button** (GPIO 23)
   - LCD displays "Starting Enroll..."
   - System auto-assigns next available ID

2. **First Scan**
   - LCD: "Place finger on sensor..."
   - Wait for confirmation beep
   - Hold finger steady on sensor

3. **Remove Finger**
   - LCD: "Remove finger"
   - Wait 2 seconds

4. **Second Scan**
   - LCD: "Place SAME finger again..."
   - Verify fingerprint matches
   
5. **Completion**
   - **Success**: "ENROLLMENT SUCCESS! User ID: X" + 3 ascending beeps
   - **Failed**: "ENROLLMENT FAILED!" + 3 error beeps
   - **Timeout**: 30 seconds if no finger detected

**Enrollment Specifications:**
- **Maximum Users**: 50 fingerprints supported
- **Enrollment Time**: ~15-30 seconds per user
- **Auto ID Assignment**: Based on template count
- **Database Full Check**: Automatic capacity monitoring
- **Template Storage**: Non-volatile sensor memory
- **Button Wiring**: GPIO 23 → Button → GND (internal pullup enabled)

### System Operation States

| State | LED Indicator | Buzzer | Description |
|---|---|---|---|
| **LOCKED** | Off | Silent | Secure state, waiting for user |
| **AUTHENTICATING** | Blinking | Short beep | Processing fingerprint |
| **OPENING** | Steady | Success tone | Door mechanism activating |
| **OPEN** | On | Silent | Cabinet accessible, monitoring motion |
| **CLOSING** | Blinking | Warning tone | Auto-close sequence active |
| **ERROR** | Fast blink | Alarm | System fault, manual intervention required |

###  **Automatic Features**

**Auto-Close System:**
- **Trigger**: 60 seconds of no motion detected
- **Warning**: LED flash and optional buzzer alert
- **Process**: Gradual door closing with safety checks
- **Override**: Motion detection cancels auto-close

**Emergency Stop:**
- **Activation**: Limit switch trigger or manual command
- **Response**: Immediate motor shutdown and error state
- **Recovery**: System reset required after clearing obstruction

---

## API & Communication

### ESP-NOW Protocol

**Communication Details:**
```cpp
// Protocol: ESP-NOW (Espressif's proprietary)
// Latency: <10ms typical
// Range: Up to 200m line-of-sight
// Pairing: MAC address-based peer connection
// Reliability: Automatic retransmission on failure
```

**Advantages over WebSocket:**
- ✅ Ultra-low latency communication
- ✅ No WiFi router dependency
- ✅ Lower power consumption
- ✅ Non-blocking operation
- ✅ Direct peer-to-peer connection

### Message Formats

**ESP-NOW Data Structure:**
```cpp
typedef struct {
    char command[32];      // Command type: "unlock", "authResult", "status"
    int userId;            // User ID from fingerprint
    bool success;          // Success/failure flag
    char data[64];         // Additional data
} ESPNowMessage;
```

**Authentication Event:**
```cpp
// Unlock Command (Host → Client)
{
  "command": "unlock",
  "userId": 12,
  "success": true,
  "data": ""
}

// Authentication Result (Host → Client)
{
  "command": "authResult",
  "userId": 5,
  "success": false,
  "data": "Access Denied"
}
}
```

**System Status:**
```json
{
  "type": "client_status",
  "timestamp": 1640995200000,
  "state": "OPEN",
  "door_open": true,
  "lock_engaged": false,
  "motion_detected": true,
  "reed_switch": false,
  "limit_switches": {
    "min": false,
    "max": false
  },
  "motors": {
    "door_running": false,
    "lock_running": false
  },
  "wifi_rssi": -45
}
```

**Command Messages:**
```json
{
  "type": "command",
  "command": "unlock_and_open",
  "user_id": 12,
  "timestamp": 1640995200000
}
```

### Emergency Commands

```json
{
  "type": "emergency",
  "command": "emergency_stop",
  "reason": "limit_switch_triggered",
  "timestamp": 1640995200000
}
```

### Diagnostic Data

```json
{
  "type": "diagnostic",
  "system_uptime": 3600000,
  "wifi_quality": 85,
  "fingerprint_database": {
    "enrolled_users": 25,
    "max_capacity": 50,
    "last_backup": 1640995200000
  },
  "motor_statistics": {
    "door_cycles": 1250,
    "lock_cycles": 1250,
    "total_runtime_hours": 12.5
  }
}
```

### Serial Command Testing Suite

The client controller includes a comprehensive serial command testing interface for validation and diagnostics. Connect via Serial Monitor at 115200 baud and use these commands:

**Available Test Commands:**
```bash
help                    # Show all available commands
test_relay              # Test relay 1 (solenoid) - ON/OFF sequence
test_motor1             # Test door motor - 2s CW, 2s CCW rotation
test_motor2             # Test lock motor - 2s CW, 2s CCW rotation
test_limit              # Test limit switches - press 3x to pass
test_motor_limit        # Motor runs until limit switch pressed (CW closing)
test_close_door         # Close door until limit switch is pressed (CW direction)
test_open_door          # Open door for CLIENT_DOOR_OPEN_STEPS (CCW direction)
test_motion             # Test PIR motion sensor - trigger to pass
test_reed               # Test reed switch - trigger to pass
```

**Test Command Details:**
- **`test_close_door`**: Runs door motor in CW direction until limit switch triggers, then stops
- **`test_open_door`**: Runs door motor in CCW direction for exactly 2000 steps (CLIENT_DOOR_OPEN_STEPS)
- **`test_motor_limit`**: Legacy command - runs motor until limit switch (CW closing direction)
- All motor tests include 30-second safety timeouts and detailed progress reporting

### Pre-Deployment Testing

**1. Hardware Verification:**
```bash
# Power Supply Test
- Verify 12V ±5% at motor drivers
- Confirm 5V ±5% at ESP32 controllers
- Check current consumption under load

# Sensor Calibration
- Test fingerprint sensor response time
- Verify motion sensor detection range
- Check reed switch activation distance
- Confirm limit switch trigger points
```

**2. Communication Testing:**
```bash
# Network Connectivity
- WiFi signal strength test (-50 dBm minimum)
- WebSocket connection stability (24-hour test)
- Message latency measurement (<100ms target)

# Inter-Controller Communication
- Command response verification
- Error handling validation  
- Reconnection testing
```

**3. Safety System Validation:**
```bash
# Emergency Stop Testing
- Limit switch activation response (<50ms)
- Manual emergency command (<100ms)
- Power failure recovery testing

# Mechanical Safety
- Door obstruction detection
- Motor stall protection
- Position verification accuracy
```

### Performance Benchmarks

| Metric | Target | Typical | Acceptance |
|---|---|---|---|
| **Authentication Time** | <2 seconds | 1.2 seconds | <3 seconds |
| **Door Open Time** | <5 seconds | 3.8 seconds | <8 seconds |
| **Door Close Time** | <5 seconds | 3.8 seconds | <8 seconds |
| **Motion Response** | <1 second | 0.3 seconds | <2 seconds |
| **WebSocket Latency** | <100ms | 45ms | <200ms |
| **Emergency Stop** | <50ms | 25ms | <100ms |

### Acceptance Testing Checklist

- [ ] **Power-on self-test passes**
- [ ] **All sensors respond correctly** 
- [ ] **Fingerprint enrollment successful**
- [ ] **Door mechanism operates smoothly**
- [ ] **Auto-close function works**
- [ ] **Emergency stop functions**
- [ ] **Network connectivity stable**
- [ ] **WebSocket communication active**
- [ ] **All safety systems operational**
- [ ] **Error recovery procedures work**

---

## Troubleshooting

### Wiring & Hardware Troubleshooting

#### Step-by-Step Connection Verification

**1. Power System Check:**
```bash
□ Main 12V supply: 11.5V - 12.5V (use multimeter)
□ Buck converter output: 4.9V - 5.1V  
□ ESP32 3.3V rail: 3.2V - 3.4V
□ All ground connections secure and continuous
□ No short circuits between power rails
```

**2. HOST Controller Verification:**
```bash
□ I2C LCD: SDA=21, SCL=22, Address 0x27
□ AS608 Sensor: TX2=17, RX2=16, 3.3V power
□ DS1302 RTC: CE=0, CLK=19, DAT=18, 5V power  
□ Buzzer: GPIO 5, active high
□ Enrollment Button: GPIO 23, pull-up enabled
```

**3. CLIENT Controller Verification:**  
```bash
□ PIR Sensor: GPIO 34 (input-only), 5V power
□ TB6600 #1: DIR=2, STEP=4, ENABLE=15
□ TB6600 #2: DIR=32, STEP=33, ENABLE=5
□ Relays: GPIO 12,13,14,27 (HIGH = active)
□ Limit Switches: GPIO 35,36 (pull-up, NO contacts)
□ Reed Switch: GPIO 39 (input-only, magnetic)
```

**4. Communication Test:**
```bash
Serial Monitor Commands:
HOST: "ESP-NOW: Host initialized"
CLIENT: "ESP-NOW: Client paired"
Both: "WiFi connected" (if using WiFi features)
```

#### Common Wiring Problems

**Issue: I2C LCD Not Working**
```bash
Symptoms: Blank display, garbled text, no backlight
Troubleshooting:
□ Verify I2C address with scanner: Wire.begin(); Wire.scan()
□ Check SDA/SCL connections (GPIO 21/22)
□ Test with 3.3V instead of 5V (some modules require 3.3V)
□ Ensure pull-up resistors present (usually on module)
Solutions:
- Try different I2C address (0x3F common alternative)
- Swap SDA/SCL if communication fails
- Add external 4.7kΩ pull-up resistors if needed
```

**Issue: Stepper Motors Erratic/Not Moving**
```bash
Symptoms: Jittery movement, wrong direction, no movement
Troubleshooting:
□ Check TB6600 DIP switch settings (current, decay mode)
□ Verify motor wiring: A+,A-,B+,B- to driver
□ Measure STEP signal: should show 3.3V pulses
□ Test ENABLE pin: LOW=enabled, HIGH=disabled
Solutions:
- Set TB6600 current to 1.5A (switches 5,6,7 = OFF,ON,OFF)
- Swap motor phase wires if direction incorrect
- Check step pulse timing (minimum 2.5μs pulse width)
```

**Issue: Fingerprint Sensor Communication Error**
```bash
Symptoms: "Sensor not found", incorrect readings
Troubleshooting:
□ Verify power: 3.3V (NOT 5V - can damage sensor)
□ Check UART wiring: ESP32 TX2→Sensor RX, ESP32 RX2→Sensor TX
□ Test baud rate: default 57600, try 9600 if issues
□ Ensure common ground connection
Solutions:
- Use voltage divider if accidentally connected to 5V
- Try hardware serial pins 1,3 instead of 16,17
- Reset sensor by power cycling
```

**Issue: ESP-NOW Communication Failed**
```bash
Symptoms: Controllers not communicating, timeout errors
Troubleshooting:
□ Both ESP32s on same WiFi channel
□ MAC addresses correctly configured
□ Distance <50 meters, clear line of sight
□ No interference from other 2.4GHz devices
Solutions:
- Scan and print MAC addresses: WiFi.macAddress()
- Force same WiFi channel with WiFi.channel()
- Use external antennas for better range
```

**Issue: Safety Switches Not Working**
```bash
Symptoms: Limit switches ignored, motors don't stop
Troubleshooting:
□ Check switch type: NO (Normally Open) required
□ Verify pull-up resistors enabled in code
□ Test switch continuity with multimeter
□ Ensure GPIO pins not shared with other functions
Solutions:
- Add external 10kΩ pull-up resistors
- Use interrupt-driven detection for faster response
- Test with LED to verify switch operation
```

#### Wiring Best Practices

**Signal Integrity:**
- Keep motor power wires away from signal wires (>2cm separation)
- Use twisted pairs for stepper motor connections
- Add ferrite cores on motor cables to reduce EMI
- Shield sensitive analog signals (if any added later)

**Power Distribution:**
- Use star grounding (single ground point) to prevent ground loops
- Add 100μF capacitors near each ESP32 for power stability  
- Install 1000μF capacitor on 12V rail for motor current spikes
- Use adequate wire gauge: 16AWG for 12V, 22AWG for 5V signals

**Connector Reliability:**
- Solder all permanent connections (avoid breadboards)
- Use screw terminals for high-current connections (>1A)
- Apply heat shrink tubing to all solder joints
- Label all wires with wire markers or heat-shrink labels

### Common Issues & Solutions

#### Power & Connectivity Issues

**Problem: ESP32 Controller Not Starting**
```bash
Symptoms: No serial output, LED indicators off
Diagnosis:
  - Check 5V power supply (measure with multimeter)
  - Verify USB cable connectivity
  - Test with known-good power source
Solutions:
  - Replace power supply if voltage <4.75V or >5.25V
  - Try different USB cable/port
  - Check for short circuits in wiring
```

**Problem: WiFi Connection Fails**
```bash
Symptoms: "WiFi connection failed" in serial monitor
Diagnosis:
  - Verify network credentials in configuration
  - Check WiFi signal strength (>-70 dBm)
  - Test with mobile hotspot
Solutions:
  - Update CLIENT_WIFI_SSID and CLIENT_WIFI_PASSWORD
  - Move device closer to router
  - Use 2.4GHz network (ESP32 limitation)
```

#### Motor & Mechanical Issues

**Problem: Stepper Motors Not Moving**
```bash
Symptoms: No motor movement, grinding sounds
Diagnosis:
  - Check TB6600 power supply (12-24V)
  - Verify STEP/DIR signal wiring
  - Test ENABLE pin state (LOW = enabled)
Solutions:
  - Measure motor supply voltage
  - Swap STEP/DIR pins if direction inverted
  - Check ENABLE pin connection (Pin 15 for Motor 1)
```

**Problem: Door Doesn't Close Properly**
```bash
Symptoms: Reed switch doesn't trigger, positioning errors
Diagnosis:
  - Check reed switch/magnet alignment
  - Verify step count accuracy
  - Test for mechanical obstructions
Solutions:
  - Adjust magnet position (5-10mm optimal gap)
  - Recalibrate CLIENT_DOOR_CLOSE_STEPS
  - Lubricate door mechanism
```

#### Sensor & Detection Issues

**Problem: Fingerprint Sensor Not Responding**
```bash
Symptoms: "Fingerprint sensor NOT found" error
Diagnosis:
  - Check Serial2 wiring (RX2:16, TX2:17)
  - Verify sensor power (3.3V or 5V depending on model)
  - Test with simple sensor library example
Solutions:
  - Swap RX/TX connections if needed
  - Check sensor power requirements
  - Replace sensor if hardware failure confirmed
```

**Problem: Motion Sensor False Triggers**
```bash
Symptoms: Excessive motion detection, auto-close not working
Diagnosis:
  - Check PIR sensor sensitivity setting
  - Verify mounting position and angle
  - Test ambient temperature variations
Solutions:
  - Adjust sensitivity potentiometer clockwise
  - Mount away from heat sources/air vents
  - Increase debounce time in software
```

#### Communication Issues

**Problem: WebSocket Connection Drops**
```bash
Symptoms: Intermittent connectivity, command delays
Diagnosis:
  - Monitor WiFi signal strength over time
  - Check router logs for disconnections
  - Verify WebSocket server on host
Solutions:
  - Implement longer reconnection timeout
  - Add WiFi signal quality monitoring
  - Use static IP assignment for stability
```

### Diagnostic Tools

#### Serial Monitor Commands
```cpp
// Add to main loop for debugging:
if (Serial.available()) {
  String command = Serial.readString();
  
  if (command == "test_motors") testMotorMovement();
  if (command == "check_sensors") printSensorStatus();
  if (command == "wifi_status") printWiFiDiagnostics();
  if (command == "reset_system") ESP.restart();
}
```

#### Hardware Testing Procedures

**Voltage Testing Points:**
```bash
# Power Supply Verification
Main Supply: 12V ±0.6V (11.4V - 12.6V acceptable)
ESP32 VIN: 5V ±0.25V (4.75V - 5.25V acceptable)  
ESP32 3.3V: 3.3V ±0.15V (3.15V - 3.45V acceptable)

# Signal Testing
STEP Pins: 0V/3.3V square wave during movement
DIR Pins: Steady 0V or 3.3V (direction dependent)
ENABLE Pins: 0V = enabled, 3.3V = disabled
```

**Sensor Verification:**
```bash
# Fingerprint Sensor (AS608)
Power: 3.3V or 5V (check sensor specification)
Communication: 57600 baud UART
Response: Sensor should respond to verifySensor() call

# Motion Sensor (PIR)  
Power: 5V (3.3V may work but reduced sensitivity)
Output: HIGH when motion detected, LOW when idle
Timing: 3-300 second trigger duration (adjustable)

# Reed Switch
Resistance: <1Ω closed, >10MΩ open
Activation: Magnet within 5-10mm distance
Wiring: Normally open contact to ESP32 input
```

### 📞 **Getting Additional Help**

If you encounter issues not covered here:

1. **Check Serial Output**: Enable debug mode and capture full startup sequence
2. **Document Error Messages**: Note exact error text and conditions when it occurs
3. **Test Individual Components**: Isolate issue to specific hardware/software component
4. **Create Minimal Test Case**: Simplify setup to reproduce issue consistently
5. **Contact Support**: Use information below with detailed problem description

---

## Maintenance

### Regular Checks
- **Weekly**: Verify door operation and sensor function
- **Monthly**: Check motor alignment and lubrication
- **Quarterly**: Inspect wiring connections and clean fingerprint sensor
- **Annually**: Replace mechanical wear components and re-enroll users

### Fingerprint Sensor Maintenance
- Keep sensor surface clean and dry
- Avoid excessive force during scanning
- Store templates periodically if sensor supports it
- Replace sensor if optical element degrades

### Motor and Mechanical Maintenance
- Check stepper motor connections and driver settings
- Verify limit switch operation and positioning
- Lubricate mechanical components as needed
- Test emergency stop functionality regularly

### Software Updates
- Monitor system logs for errors
- Update WiFi credentials if network changes
- Adjust timing parameters based on usage patterns
- Update motor parameters if hardware changes

---

## Fingerprint Management

### Enrolling New Users
1. Long-press the tactile button (5+ seconds) to enter enrollment mode
2. Follow LCD prompts to scan finger twice
3. Note the assigned ID number
4. Test authentication immediately

### Managing Stored Templates
- **View Count**: Use `count` command to see enrolled users
- **Delete User**: Use `delete <ID>` to remove specific fingerprint
- **Clear Database**: Use `empty` to remove all fingerprints
- **Check Capacity**: Sensor supports up to 50 templates

### Best Practices
- Enroll users with clean, dry fingers
- Avoid enrolling the same finger multiple times
- Regularly clean sensor surface
- Test authentication after enrollment
- Keep backup of enrolled user IDs

---

## Security Considerations

### Authentication Security
- **Biometric Data**: Fingerprints stored locally on sensor only
- **Template Protection**: No reverse-engineering of original fingerprint possible
- **Enrollment Control**: Restrict enrollment mode to authorized personnel
- **Access Logging**: Track authentication attempts with timestamps

### Physical Security
- **Tamper Protection**: Protect ESP32 and sensor from physical access
- **Cable Security**: Secure wiring to prevent disconnection
- **Environmental Protection**: Use enclosures for weather/water protection
- **Power Security**: Backup power for critical operations

### Network Security
- **ESP-NOW**: Direct peer-to-peer communication (no internet exposure)
- **WiFi Usage**: Only for NTP time sync (optional)
- **Local Network**: Keep controllers on secure local network
- **Firmware Security**: Keep ESP32 firmware updated

---

## Development and Customization

### Adding New Features
1. **Sensor Integration**: Create new sensor classes following existing patterns
2. **Motor Control**: Extend TB6600 class for additional motors
3. **Communication**: Add new ESP-NOW message types
4. **User Interface**: Modify LCD displays and buzzer patterns

### Code Structure Guidelines
- **Modular Design**: Keep functions focused and reusable
- **Error Handling**: Implement proper error checking and recovery
- **Documentation**: Comment code and update README for changes
- **Testing**: Add test commands for new features

### Hardware Modifications
- **Pin Changes**: Update pin definitions in respective header files
- **Component Swaps**: Modify initialization code for different components
- **Power Requirements**: Recalculate power needs for additions
- **Safety Systems**: Ensure emergency stops work with modifications

### Performance Tuning
- **Motor Speeds**: Adjust pulse timing for optimal performance
- **Sensor Sensitivity**: Calibrate PIR and limit switch parameters
- **Communication Timing**: Optimize ESP-NOW message intervals
- **Memory Usage**: Monitor ESP32 RAM and flash usage

---

## Project Structure

```
Smart-Cabinet/
├── 📁 source/
│   ├── 📁 host/SmartCabinet/              # HOST Controller (Authentication)
│   │   ├── SmartCabinet.ino               # Main host program
│   │   ├── pins.h                         # Host pin configuration
│   │   ├── I2CLcd.h/.cpp                  # LCD display driver
│   │   ├── FingerprintAS608.h/.cpp        # Biometric sensor interface
│   │   ├── DS1302Rtc.h/.cpp               # Real-time clock module
│   │   ├── Buzzer.h/.cpp                  # Audio feedback system
│   │   └── WebSocketServer.h/.cpp         # Network communication server
│   │
│   └── 📁 client/SmartCabinet/            # CLIENT Controller (Mechanical)
│       ├── SmartCabinet.ino               # Main client program  
│       ├── client_pins.h                  # Client pin configuration
│       ├── MotionSensor.h/.cpp            # PIR motion detection
│       ├── TB6600.h/.cpp                  # Stepper motor drivers
│       ├── Relay4.h/.cpp                  # Relay board control
│       ├── LimitSwitch.h/.cpp             # Safety switch handling
│       ├── ReedSwitch.h/.cpp              # Position sensing
│       ├── WebSocketClient.h/.cpp         # Network communication client
│       └── README.md                      # Client-specific documentation
│
├── 📁 diagram/                            # System Documentation
│   └── img20.jpg                          # Complete wiring diagram
│
├── 📁 model/                              # Design & 3D Models
│   ├── Cabinet_Actuator_Mount.png         # Actuator mount design preview
│   ├── Cabinet_Actuator_Mount.stl         # 3D printable actuator mounting bracket
│   ├── Cabinet_Door_Puller_Mount.png      # Door puller mount design preview
│   ├── Cabinet_Door_Puller_Mount.stl      # 3D printable door puller mounting bracket
│   ├── CE3V3SE_Cabinet_Door_Puller_Mount.gcode # Ready-to-print door puller mount (Creality Ender 3 V3 SE)
│   ├── Cabinet_Scanner_Case.png           # Scanner case design preview
│   ├── Cabinet_Scanner_Case.stl           # 3D printable fingerprint scanner enclosure
│   ├── Cabinet_Scanner_Case_Mount.png     # Scanner mount design preview
│   ├── Cabinet_Scanner_Case_Mount.stl     # 3D printable mounting bracket
│   ├── Cabinet_Scanner_Case_Cover.png     # Scanner case cover design preview
│   ├── Cabinet_Scanner_Case_Cover.stl     # 3D printable protective cover for scanner case
│   ├── CE3V3SE_Cabinet_Scanner_Case_Cover.gcode # Ready-to-print scanner case cover (Creality Ender 3 V3 SE)
│   ├── Cabinet_Stepper_Mount.gcode        # Ready-to-print stepper mount (Creality Ender 3 V3 SE)
│   ├── Cabinet_Stepper_Mount.stl          # 3D printable stepper motor mount
│   ├── CE3V3SE_Cabinet_Scanner_Case.gcode # Ready-to-print scanner case (Creality Ender 3 V3 SE)
│   ├── CE3V3SE_Cabinet_Scanner_Case_Mount.gcode # Ready-to-print mount (Creality Ender 3 V3 SE)
│   ├── CE3V3SE_Cabinet_Stepper_Mount_And_Bearing_Mount.gcode # Ready-to-print stepper and bearing mount (Creality Ender 3 V3 SE)
│   ├── Cabinet_Bearing_Mount.png          # Bearing mount design preview
│   ├── Cabinet_Bearing_Mount.stl          # 3D printable bearing mounting bracket
│   ├── CE3V3SE_Cabinet_Bearing_Mount.gcode # Ready-to-print bearing mount (Creality Ender 3 V3 SE)
│   ├── Cabinet_Limit_Switch_Mount.png     # Limit switch mount design preview
│   ├── Cabinet_Limit_Switch_Mount.stl     # 3D printable limit switch mounting bracket
│   ├── Cabinet_Limit_Switch_Mount_Cover.stl # Protective cover for limit switch mount
│   ├── CE3V3SE_Cabinet_Limit_Switch_Mount_Cover.gcode # Ready-to-print limit switch mount cover (Creality Ender 3 V3 SE)
│   ├── CE3V3SE_Cabinet_Limit_Switch_Mount.gcode # Ready-to-print limit switch mount (Creality Ender 3 V3 SE)
│   ├── Cabinet_Stick_Mount.png            # Stick mount design preview
│   ├── Cabinet_Stick_Mount.stl            # 3D printable stick mounting bracket
│   ├── CE3V3SE_Cabinet_Stick_Mount.gcode  # Ready-to-print stick mount (Creality Ender 3 V3 SE)
│   ├── Cabinet_Motion_Sensor_Mount.png    # Motion sensor mount design preview
│   ├── Cabinet_Motion_Sensor_Mount.stl    # 3D printable motion sensor mounting bracket
│   ├── CE3V3SE_Cabinet_Motion_Sensor_Mount.gcode # Ready-to-print motion sensor mount (Creality Ender 3 V3 SE)
│   ├── Cabinet_Motion_Sensor_Mount_Cover.stl # Protective cover for motion sensor mount
│   ├── SmartCabinet v0.png                # Initial concept design
│   ├── SmartCabinet v03.png               # Design iteration 3
│   └── SmartCabinet v4.png                # Final design version
├── README.md                              # Main project documentation
└── LICENSE                                # Project license file
```

### Architecture Overview

**HOST Controller Components:**
- `SmartCabinet.ino`: Main application logic and state management
- `I2CLcd.*`: 20x4 character display driver with I2C interface
- `FingerprintAS608.*`: Biometric sensor communication and authentication
- `DS1302Rtc.*`: Real-time clock for timestamp and scheduling
- `Buzzer.*`: PWM-driven audio feedback system  
- `WebSocketServer.*`: Network communication hub

**CLIENT Controller Components:**
- `SmartCabinet.ino`: Mechanical control and safety systems
- `MotionSensor.*`: PIR motion detection with debouncing
- `TB6600.*`: Stepper motor control with non-blocking operation
- `Relay4.*`: Multi-channel relay board for high-power switching
- `LimitSwitch.*`: Safety switch monitoring with interrupt handling
- `ReedSwitch.*`: Magnetic door position sensing
- `WebSocketClient.*`: Network communication with auto-reconnection

### Component Responsibilities

| Component | Primary Function | Secondary Function |
|---|---|---|
| **HOST Controller** | User authentication & interface | System coordination & logging |
| **CLIENT Controller** | Mechanical operations & safety | Environmental monitoring |
| **WebSocket Layer** | Real-time communication | Status reporting & diagnostics |
| **Safety Systems** | Emergency protection | Preventive maintenance alerts |
| **Motor Control** | Precise positioning | Load monitoring & protection |

---

## Future Enhancements

### Mobile Application Integration
- **Native App Development**: iOS/Android companion app for remote monitoring
- **Push Notifications**: Real-time alerts for security events and system status
- **Remote Control**: Emergency unlock and system management capabilities
- **User Management**: Fingerprint enrollment and access control via mobile interface

### Advanced AI Features
- **Behavioral Analytics**: Machine learning-based user pattern recognition
- **Predictive Maintenance**: AI-driven component health monitoring and failure prediction
- **Adaptive Security**: Dynamic access control based on time, location, and user behavior
- **Voice Control**: Integration with voice assistants for hands-free operation

### Enhanced Security Systems
- **Multi-Factor Authentication**: Combination of fingerprint, RFID, and PIN verification
- **Facial Recognition**: Computer vision-based secondary authentication
- **Tamper Detection**: Advanced intrusion detection with immediate alert systems
- **Encrypted Communication**: End-to-end encryption for all network communications

### IoT Ecosystem Integration
- **Home Automation**: Integration with existing smart home platforms (Home Assistant, OpenHAB)
- **Cloud Connectivity**: Secure cloud backup and remote access capabilities
- **API Gateway**: RESTful API for third-party system integration
- **Dashboard Interface**: Web-based management interface for system administration

### Performance Optimizations
- **Edge Computing**: Local AI processing for faster response times
- **Energy Management**: Advanced power saving modes and solar charging compatibility
- **Wireless Charging**: Contactless power delivery for maintenance-free operation
- **Mesh Networking**: Multi-device communication for scaled deployments

### User Experience Improvements
- **Customizable Interface**: Themeable LCD displays and configurable audio feedback
- **Multi-Language Support**: Internationalization for global deployment
- **Accessibility Features**: Voice prompts and tactile feedback for visually impaired users
- **Progressive Web App**: Browser-based configuration and monitoring interface

---

## Contributing

We welcome contributions from the community! Here's how you can help improve the Smart Cabinet System:

### Development Setup

1. **Fork the Repository**
   ```bash
   git clone https://github.com/qppd/Smart-Cabinet.git
   cd Smart-Cabinet
   git checkout -b feature/your-feature-name
   ```

2. **Development Environment**
   ```bash
   # Install required tools
   - Arduino IDE 2.0+ or PlatformIO
   - ESP32 Board Package
   - Required libraries (see dependencies section)
   ```

3. **Testing Setup**
   ```bash
   # Hardware requirements for testing
   - 2x ESP32 development boards
   - Breadboard and jumper wires for prototyping
   - Basic multimeter for voltage verification
   ```

### Contribution Guidelines

**Code Standards:**
- Follow Arduino/C++ naming conventions
- Add comprehensive comments for complex logic
- Include header documentation for all new functions
- Maintain consistent indentation (2 spaces)

**Documentation:**
- Update README.md for new features
- Add inline code comments for complex algorithms
- Include wiring diagrams for hardware changes
- Provide configuration examples

**Testing Requirements:**
- Test all new features on actual hardware
- Verify compatibility with existing functionality
- Include performance benchmarks for optimizations
- Document any breaking changes

### Priority Areas for Contribution

1. **Hardware Drivers**: New sensor and actuator support
2. **Communication Protocols**: Additional network interfaces
3. **Security Features**: Enhanced authentication methods
4. **User Interface**: Improved display and interaction systems
5. **Documentation**: Installation guides and troubleshooting
6. **Testing**: Automated testing frameworks and validation scripts

### Submission Process

1. **Create Feature Branch**: Use descriptive branch names
2. **Implement Changes**: Follow coding standards and add tests
3. **Update Documentation**: Include relevant documentation updates
4. **Submit Pull Request**: Provide detailed description of changes
5. **Review Process**: Collaborate with maintainers on feedback
6. **Merge Approval**: Final testing and integration

---

## Support & Contact

### Project Maintainer

**QPPD (Sajed Mendoza)**
- Portfolio: [sajed-mendoza.onrender.com](https://sajed-mendoza.onrender.com)
- GitHub: [@qppd](https://github.com/qppd)
- Email: quezon.province.pd@gmail.com

### Community & Social

- Facebook Developer Page: [QPPD Dev](https://facebook.com/qppd.dev)
- Organization: [Quezon Province Programmer/Developers](https://facebook.com/QUEZONPROVINCEDEVS)

### Technical Support

For Technical Issues:
1. **Search Existing Issues**: Check [GitHub Issues](https://github.com/qppd/Smart-Cabinet/issues)
2. **Create New Issue**: Use provided templates for bug reports or feature requests
3. **Include Information**: Hardware setup, error messages, and reproduction steps
4. **Response Time**: 24-48 hours for initial response

For General Questions:
- **Email Support**: Include "Smart Cabinet" in subject line
- **Community Forum**: Post in Facebook developer group
- **Live Chat**: Available on portfolio website during business hours

### Additional Resources

#### 3D Printable Components

All 3D models are available in the [model directory](https://github.com/qppd/Smart-Cabinet/tree/main/model) with ready-to-print files.

**Fingerprint Scanner Enclosure:**

<div align="center">
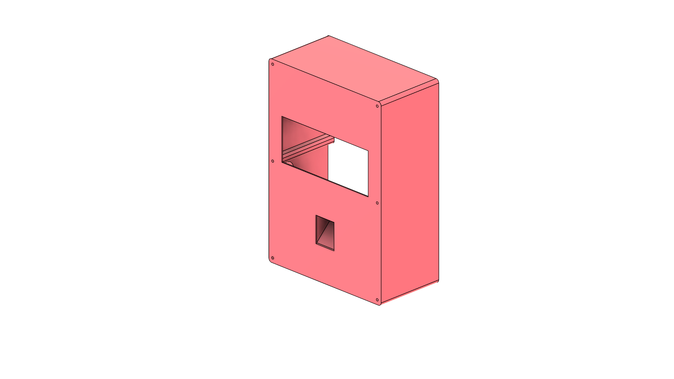
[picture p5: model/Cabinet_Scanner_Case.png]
Cabinet Scanner Case Preview
  
</div>

- **Files Available:**
  - `Cabinet_Scanner_Case.stl` - 3D model for any slicer software
  - `Cabinet_Scanner_Case.png` - Preview/reference image
  - `CE3V3SE_Cabinet_Scanner_Case.gcode` - Pre-sliced for Creality Ender 3 V3 SE
  
- **Purpose:** Protective enclosure for AS608/R307 fingerprint sensor
- **Features:**
  - Secure sensor mounting with snap-fit design
  - Wire management channels for clean installation
  - Professional appearance for cabinet integration
  - Compatible with standard fingerprint sensor modules

**Scanner Mounting Bracket:**

<div align="center">
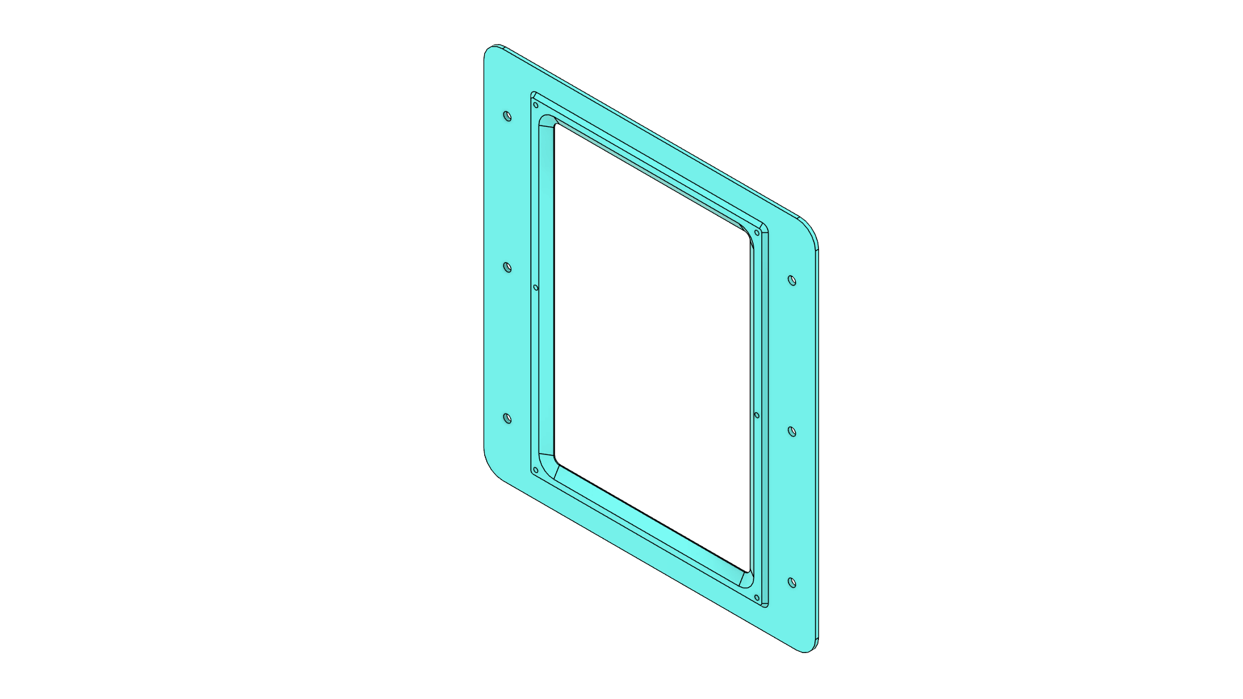
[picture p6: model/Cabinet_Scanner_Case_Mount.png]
Cabinet Scanner Case Mount Preview
  
</div>

- **Files Available:**
  - `Cabinet_Scanner_Case_Mount.stl` - 3D model for any slicer software
  - `Cabinet_Scanner_Case_Mount.png` - Preview/reference image
  - `CE3V3SE_Cabinet_Scanner_Case_Mount.gcode` - Pre-sliced for Creality Ender 3 V3 SE
  
- **Purpose:** Secure mounting bracket for scanner case attachment
- **Features:**
  - Adjustable positioning for optimal finger placement
  - Screw mounting points for permanent installation
  - Compatible with various cabinet materials
  - Lightweight yet sturdy construction

**Scanner Case Cover:**

<div align="center">
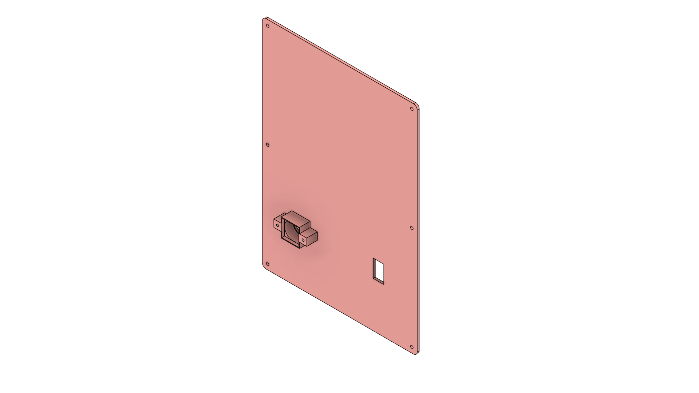
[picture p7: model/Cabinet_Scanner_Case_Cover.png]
Cabinet Scanner Case Cover Preview
  
</div>

- **Files Available:**
  - `Cabinet_Scanner_Case_Cover.stl` - 3D model for any slicer software
  - `Cabinet_Scanner_Case_Cover.png` - Preview/reference image
  - `CE3V3SE_Cabinet_Scanner_Case_Cover.gcode` - Pre-sliced for Creality Ender 3 V3 SE
  
- **Purpose:** Protective cover for the fingerprint scanner case
- **Features:**
  - Secure fit over the scanner enclosure
  - Environmental protection for sensitive components
  - Easy removal for maintenance access
  - Professional appearance integration

**Actuator Mount:**

<div align="center">
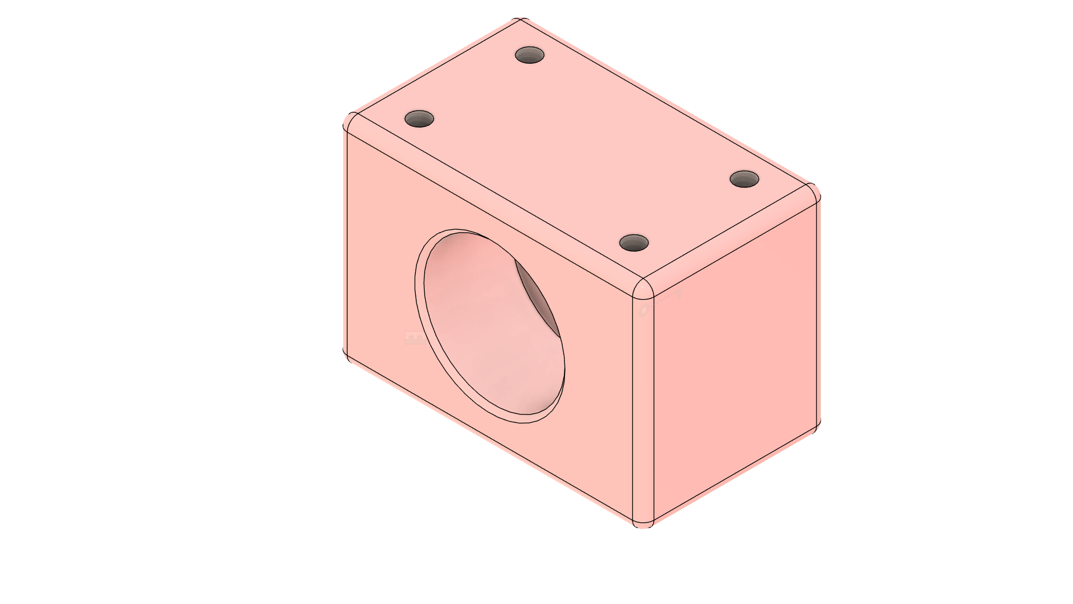
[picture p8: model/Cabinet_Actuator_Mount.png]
Cabinet Actuator Mount Preview
  
</div>

- **Files Available:**
  - `Cabinet_Actuator_Mount.stl` - 3D model for any slicer software
  - `Cabinet_Actuator_Mount.png` - Preview/reference image

- **Purpose:** Mounting bracket for cabinet actuator/linear actuator
- **Features:**
  - Robust design for secure actuator installation
  - Multiple mounting holes for flexible placement
  - Designed for easy integration with cabinet frame

**Door Puller Mount:**

<div align="center">
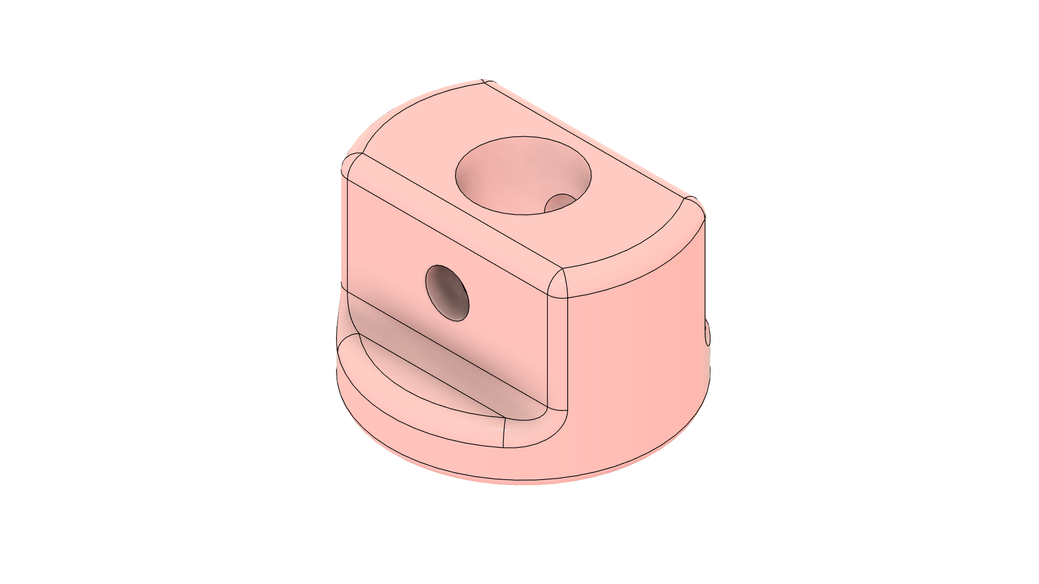
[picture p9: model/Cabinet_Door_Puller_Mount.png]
Cabinet Door Puller Mount Preview
  
</div>

- **Files Available:**
  - `Cabinet_Door_Puller_Mount.stl` - 3D model for any slicer software
  - `Cabinet_Door_Puller_Mount.png` - Preview/reference image
  - `CE3V3SE_Cabinet_Door_Puller_Mount.gcode` - Pre-sliced for Creality Ender 3 V3 SE

- **Purpose:** Mounting bracket for door pulling mechanism
- **Features:**
  - Designed for smooth door opening operation
  - Reinforced structure for reliable performance
  - Easy installation on cabinet frame
  - Compatible with various actuator types

**Stepper Motor Mount:**

- **Files Available:**
  - `Cabinet_Stepper_Mount.stl` - 3D model for any slicer software
  - `Cabinet_Stepper_Mount.gcode` - Pre-sliced for Creality Ender 3 V3 SE
  - `CE3V3SE_Cabinet_Stepper_Mount_And_Bearing_Mount.gcode` - Pre-sliced stepper and bearing mount (Creality Ender 3 V3 SE)

- **Purpose:** Mount for stepper motor used in cabinet locking or actuation
- **Features:**
  - Precise fit for NEMA stepper motors
  - Rigid structure for vibration reduction
  - Easy mounting to cabinet or enclosure
  - Includes integrated bearing mount for additional support

**Bearing Mount:**

<div align="center">
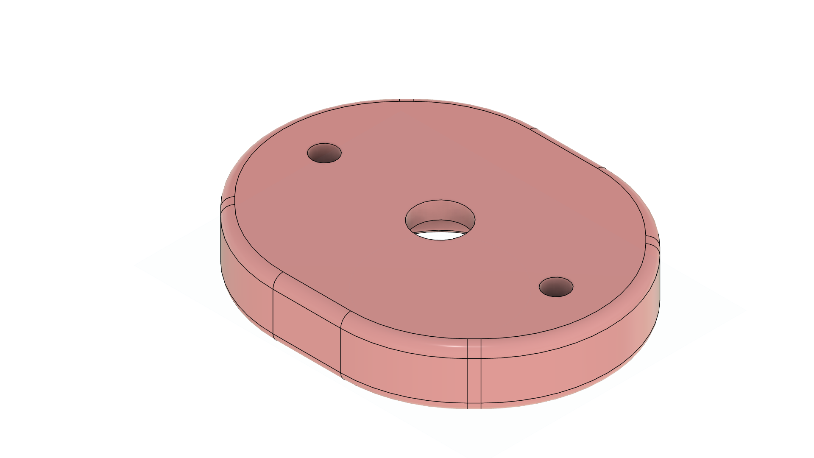
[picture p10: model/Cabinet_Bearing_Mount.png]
Cabinet Bearing Mount Preview
  
</div>

- **Files Available:**
  - `Cabinet_Bearing_Mount.stl` - 3D model for any slicer software
  - `Cabinet_Bearing_Mount.png` - Preview/reference image
  - `CE3V3SE_Cabinet_Bearing_Mount.gcode` - Pre-sliced for Creality Ender 3 V3 SE
  
- **Purpose:** Mounting bracket for bearings used in mechanical assemblies
- **Features:**
  - Secure bearing housing for smooth rotation
  - Compatible with standard bearing sizes
  - Easy integration with cabinet frame
  - Durable design for long-term reliability

**Limit Switch Mount:**

<div align="center">
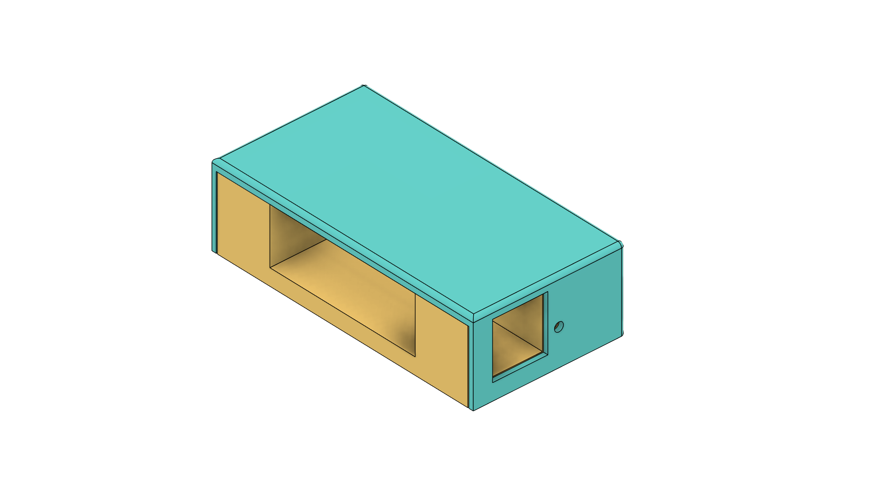
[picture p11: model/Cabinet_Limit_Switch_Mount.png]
Cabinet Limit Switch Mount Preview
  
</div>

- **Files Available:**
  - `Cabinet_Limit_Switch_Mount.stl` - 3D model for any slicer software
  - `Cabinet_Limit_Switch_Mount.png` - Preview/reference image
  - `CE3V3SE_Cabinet_Limit_Switch_Mount.gcode` - Pre-sliced for Creality Ender 3 V3 SE
  
- **Purpose:** Mounting bracket for limit switches in automated systems
- **Features:**
  - Precise positioning for accurate switch activation
  - Screw mounting for secure installation
  - Compatible with standard limit switch modules

**Limit Switch Mount Cover:**

- **Files Available:**
  - `Cabinet_Limit_Switch_Mount_Cover.stl` - Protective cover for limit switch mount
  - `CE3V3SE_Cabinet_Limit_Switch_Mount_Cover.gcode` - Pre-sliced for Creality Ender 3 V3 SE
  
- **Purpose:** Environmental protection for limit switch mounting assembly
- **Features:**
  - Secure fit over the limit switch mount
  - Protection from dust and moisture
  - Easy installation and removal
  - Maintains professional appearance

**Stick Mount:**

<div align="center">
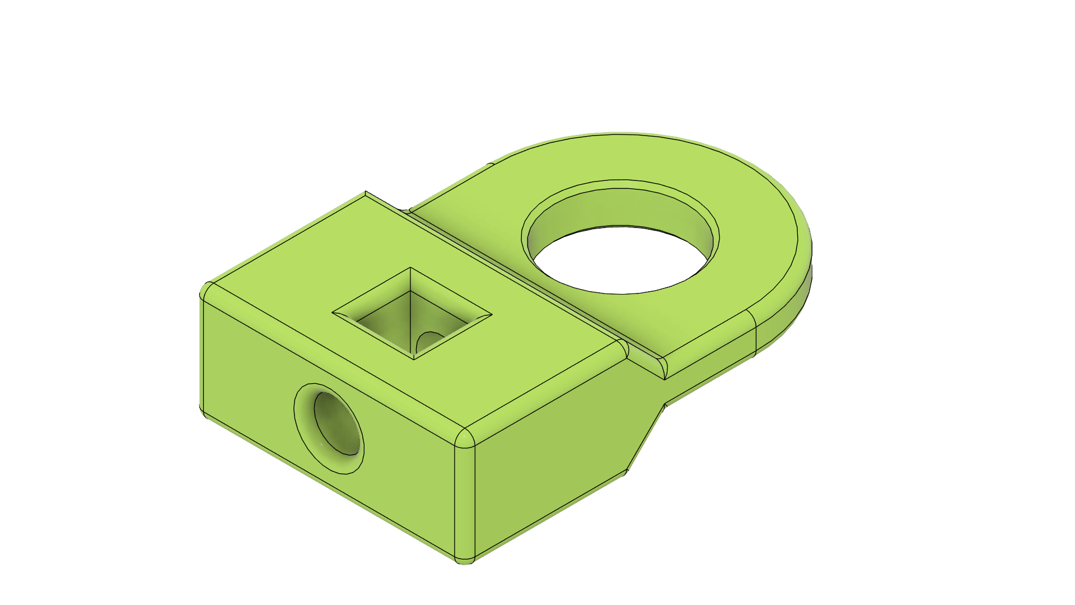
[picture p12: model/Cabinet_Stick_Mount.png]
Cabinet Stick Mount Preview
  
</div>

- **Files Available:**
  - `Cabinet_Stick_Mount.stl` - 3D model for any slicer software
  - `Cabinet_Stick_Mount.png` - Preview/reference image
  - `CE3V3SE_Cabinet_Stick_Mount.gcode` - Pre-sliced for Creality Ender 3 V3 SE
  
- **Purpose:** Mounting bracket for rods or sticks in mechanical linkages
- **Features:**
  - Adjustable mounting for flexible positioning
  - Robust construction for load-bearing applications
  - Easy assembly with standard fasteners
  - Designed for smooth operation in cabinet mechanisms

**Motion Sensor Mount:**

<div align="center">
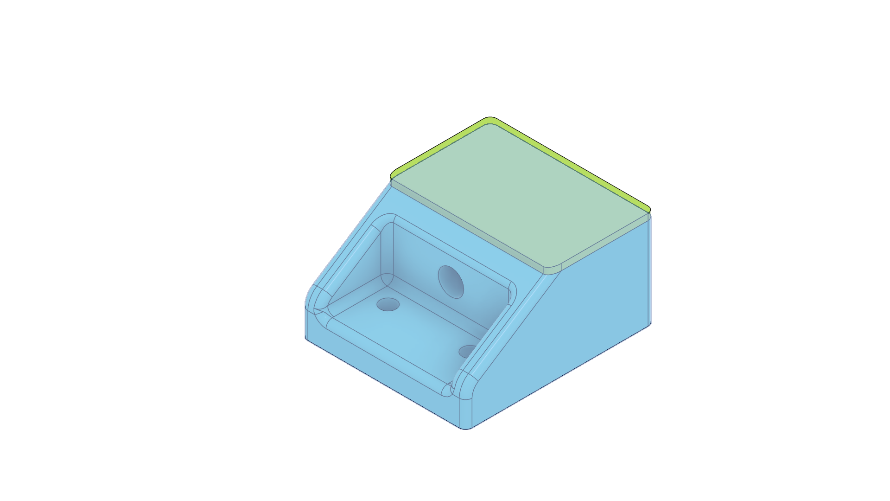
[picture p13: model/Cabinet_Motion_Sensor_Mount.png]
Cabinet Motion Sensor Mount Preview
  
</div>

- **Files Available:**
  - `Cabinet_Motion_Sensor_Mount.stl` - 3D model for any slicer software
  - `Cabinet_Motion_Sensor_Mount.png` - Preview/reference image
  - `CE3V3SE_Cabinet_Motion_Sensor_Mount.gcode` - Pre-sliced for Creality Ender 3 V3 SE
  
- **Purpose:** Mounting bracket for motion sensors in automated systems
- **Features:**
  - Optimal positioning for motion detection
  - Secure mounting for reliable operation
  - Compatible with standard motion sensor modules
  - Adjustable angle for customized coverage

**Motion Sensor Mount Cover:**

- **Files Available:**
  - `Cabinet_Motion_Sensor_Mount_Cover.stl` - Protective cover for motion sensor mount
  
- **Purpose:** Environmental protection for motion sensor mounting assembly
- **Features:**
  - Secure fit over the motion sensor mount
  - Protection from dust and environmental factors
  - Easy installation and removal
  - Maintains professional appearance

**Printing Recommendations:**
- **Material:** PLA or PETG recommended
- **Layer Height:** 0.2mm for optimal detail
- **Infill:** 20-30% for structural integrity
- **Supports:** May be required depending on orientation
- **Print Time:** Scanner case ~2-3 hours, mount ~1-2 hours

**Design Iterations:**
- `SmartCabinet v0.png` - Initial concept and planning
- `SmartCabinet v03.png` - Refined design with improvements
- `SmartCabinet v4.png` - Final production-ready design

## License

### MIT License

```
MIT License

Copyright (c) 2025 QPPD (Sajed Mendoza)

Permission is hereby granted, free of charge, to any person obtaining a copy
of this software and associated documentation files (the "Software"), to deal
in the Software without restriction, including without limitation the rights
to use, copy, modify, merge, publish, distribute, sublicense, and/or sell
copies of the Software, and to permit persons to whom the Software is
furnished to do so, subject to the following conditions:

The above copyright notice and this permission notice shall be included in all
copies or substantial portions of the Software.

THE SOFTWARE IS PROVIDED "AS IS", WITHOUT WARRANTY OF ANY KIND, EXPRESS OR
IMPLIED, INCLUDING BUT NOT LIMITED TO THE WARRANTIES OF MERCHANTABILITY,
FITNESS FOR A PARTICULAR PURPOSE AND NONINFRINGEMENT. IN NO EVENT SHALL THE
AUTHORS OR COPYRIGHT HOLDERS BE LIABLE FOR ANY CLAIM, DAMAGES OR OTHER
LIABILITY, WHETHER IN AN ACTION OF CONTRACT, TORT OR OTHERWISE, ARISING FROM,
OUT OF OR IN CONNECTION WITH THE SOFTWARE OR THE USE OR OTHER DEALINGS IN THE
SOFTWARE.
```

### License Terms

**Permissions:**
- Modification: Customize and extend functionality
- Distribution: Share modified versions with others
- Private Use: Use for personal projects and learning

**Conditions:**
- License Notice: Include original license in distributions
- Copyright Notice: Credit original author in derivative works

**Limitations:**
- Warranty: Software provided "as-is" without guarantees

### Educational Use

This project is specifically designed to be educational and learning-friendly:

- **Academic Projects**: Free use in schools, universities, and research institutions
- **STEM Education**: Encourage use in robotics and IoT curriculum  
- **Maker Spaces**: Support community workshops and maker initiatives
- **Open Source**: Promote collaborative development and knowledge sharing

### Commercial Licensing

For commercial deployments requiring additional support or custom licensing:

- **Volume Licensing**: Special terms for large-scale deployments
- **OEM Integration**: White-label licensing for product manufacturers

**Contact**: quezon.province.pd@gmail.com for commercial licensing inquiries.

---

<div align="center">

### Thank you for choosing Smart Cabinet System!

*Building the future of secure, intelligent storage solutions.*

**Star this repository if it helped you!**

</div>

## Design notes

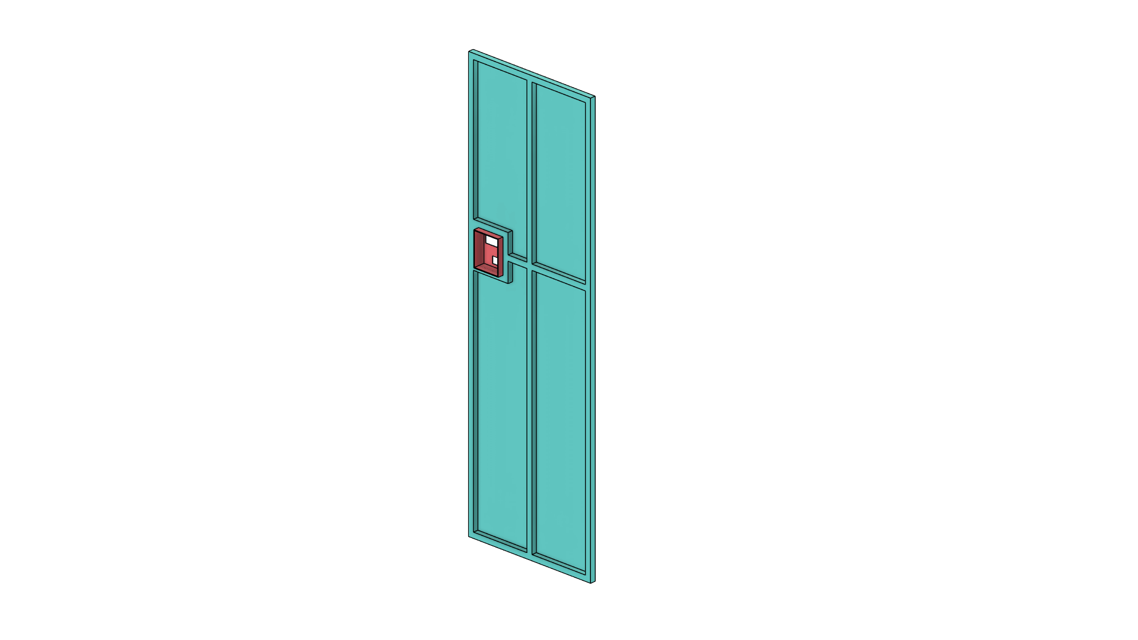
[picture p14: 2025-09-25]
model/SmartCabinet v0.png

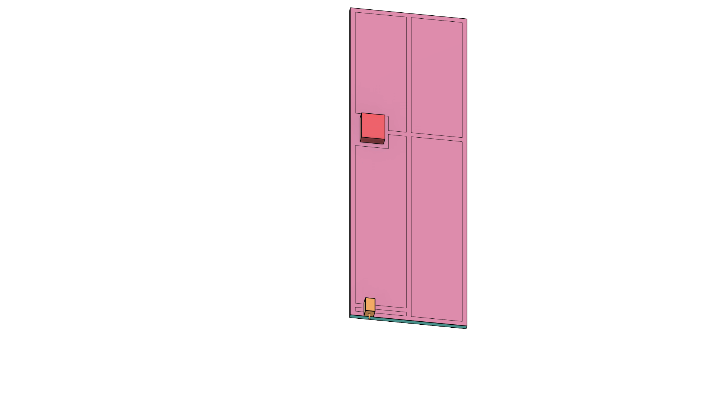
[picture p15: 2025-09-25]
model/SmartCabinet v4.png

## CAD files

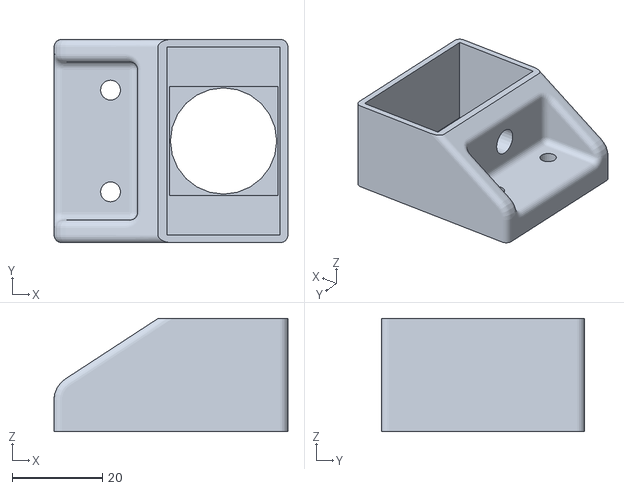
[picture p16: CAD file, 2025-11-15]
model/Cabinet_Motion_Sensor_Mount.stl
51.8 x 45.0 x 25.0

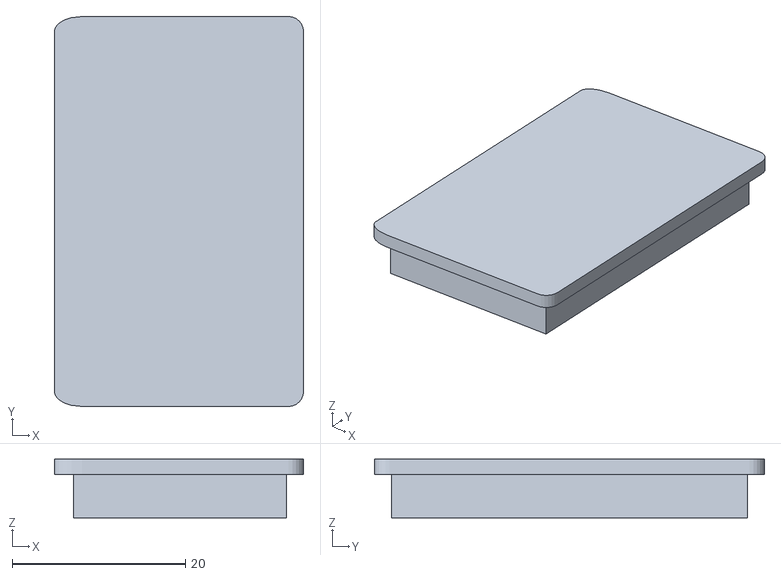
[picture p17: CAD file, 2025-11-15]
model/Cabinet_Motion_Sensor_Mount_Cover.stl
28.8 x 45.0 x 6.75

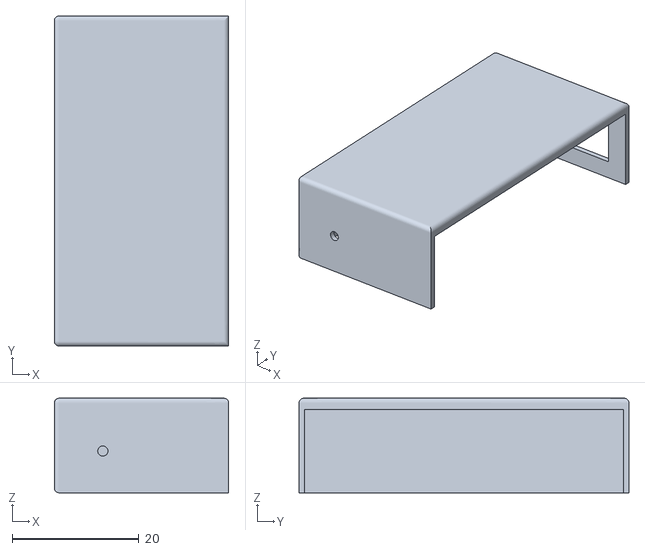
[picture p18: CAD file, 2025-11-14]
model/Cabinet_Limit_Switch_Mount_Cover.stl
27.6 x 52.2 x 14.9

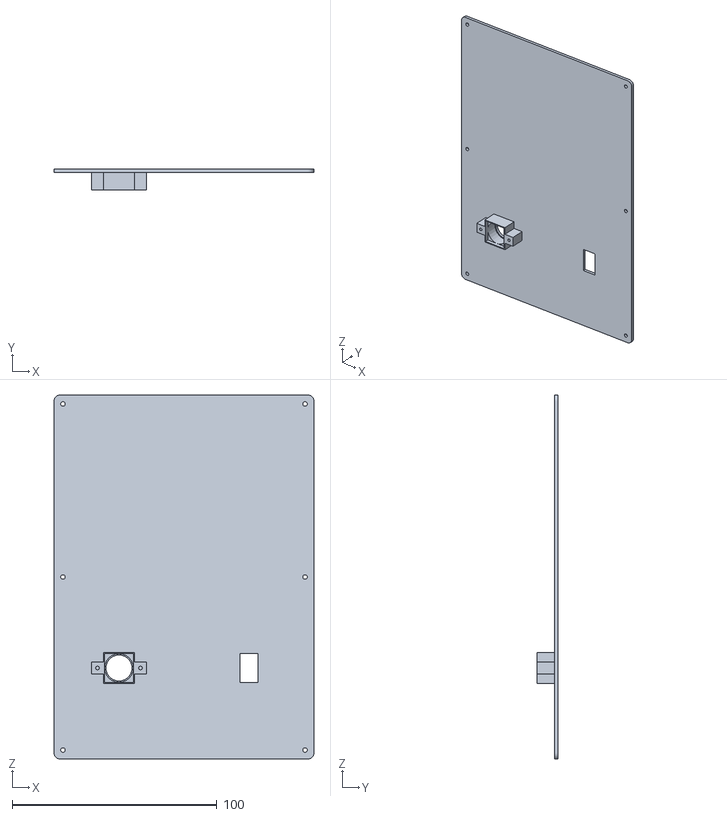
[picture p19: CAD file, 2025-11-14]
model/Cabinet_Scanner_Case_Cover.stl
127.0 x 10.5 x 177.8

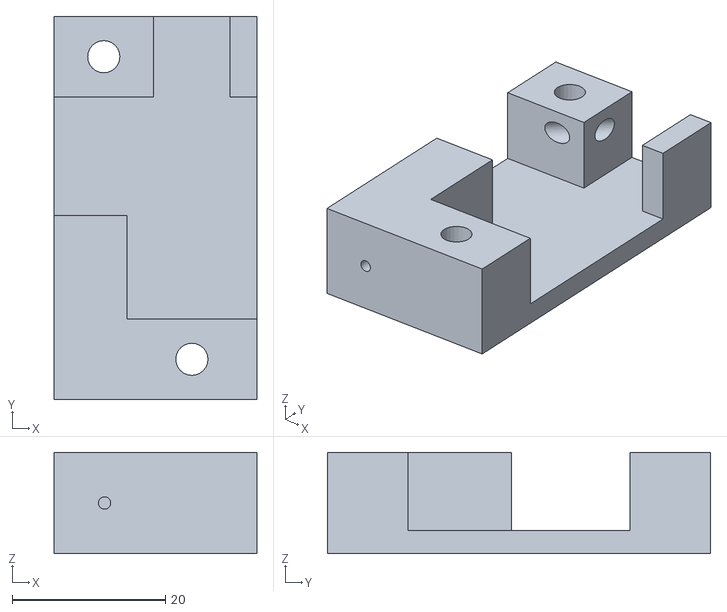
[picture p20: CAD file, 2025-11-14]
model/Cabinet_Limit_Switch_Mount.stl
26.5 x 50.0 x 13.2

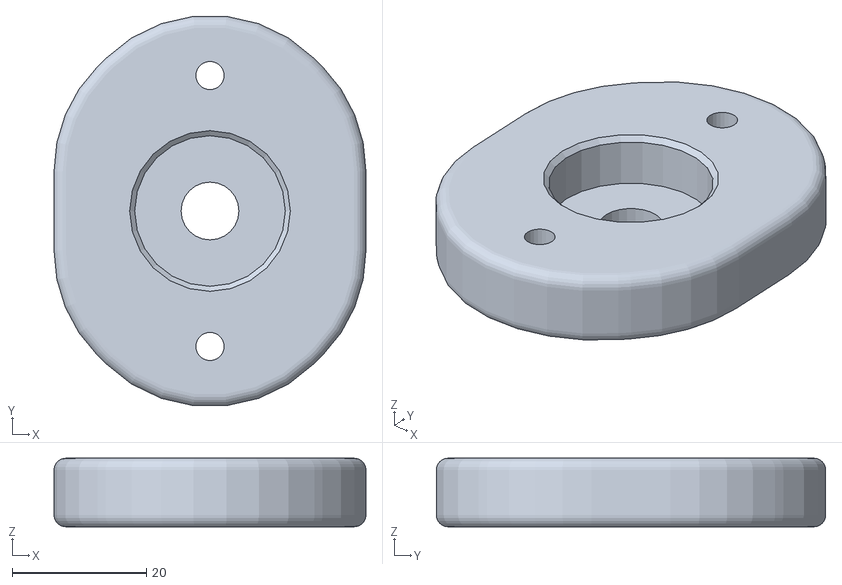
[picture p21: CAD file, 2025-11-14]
model/Cabinet_Bearing_Mount.stl
46.4 x 57.9 x 10.2

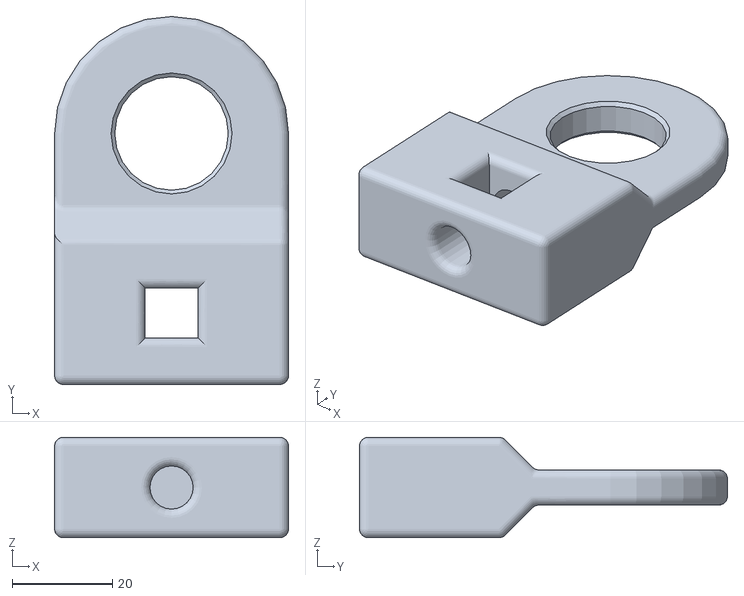
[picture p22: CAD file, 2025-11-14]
model/Cabinet_Stick_Mount.stl
46.6 x 73.3 x 20.0

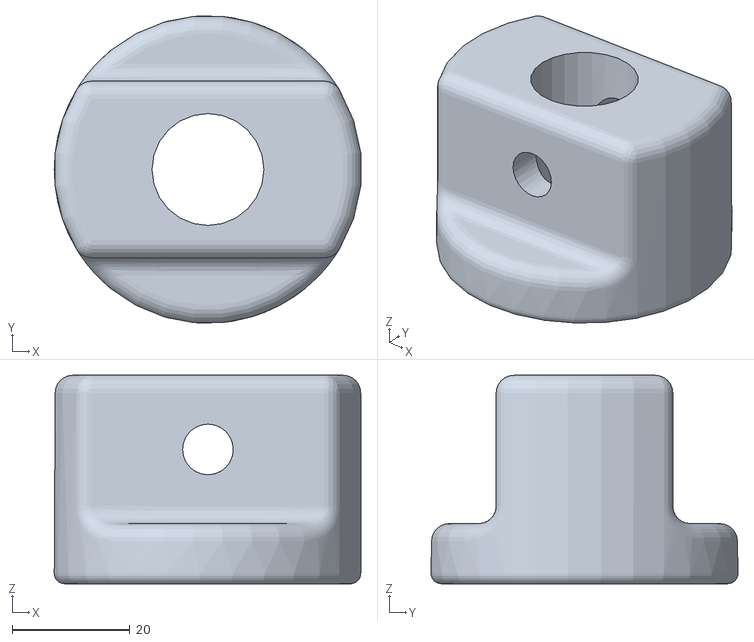
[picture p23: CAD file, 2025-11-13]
model/Cabinet_Door_Puller_Mount.stl
52.0 x 52.1 x 35.4

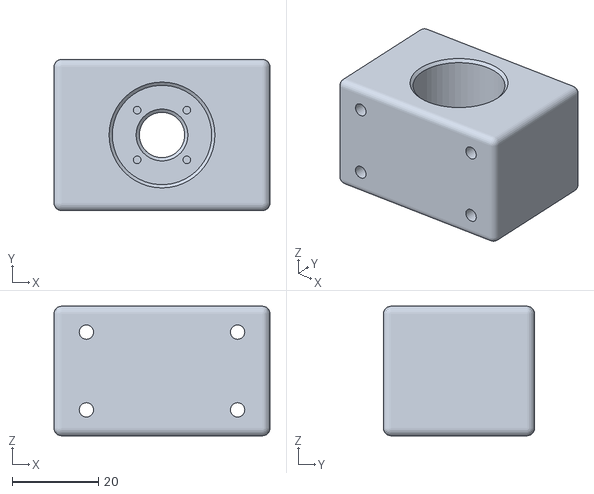
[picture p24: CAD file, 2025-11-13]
model/Cabinet_Actuator_Mount.stl
50.0 x 35.0 x 30.0

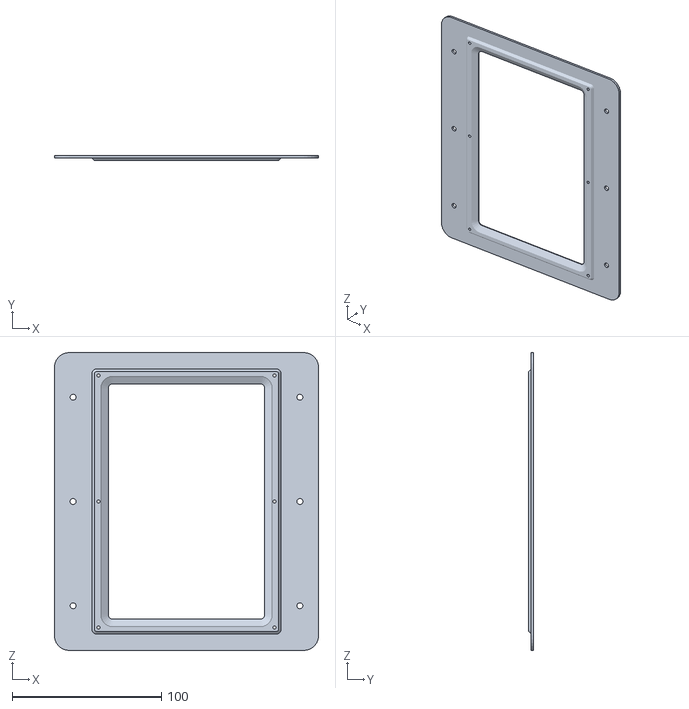
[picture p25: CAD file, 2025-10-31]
model/Cabinet_Scanner_Case_Mount.stl
177.4 x 3.50 x 200.0

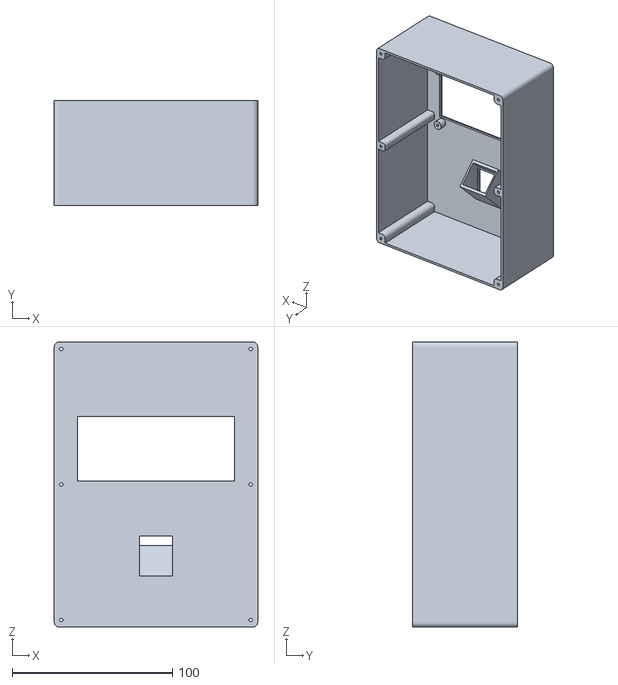
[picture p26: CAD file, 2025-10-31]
model/Cabinet_Scanner_Case.stl
127.0 x 65.2 x 177.8

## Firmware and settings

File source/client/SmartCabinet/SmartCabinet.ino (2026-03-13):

/*
  ===============================================
  SMART CABINET CLIENT CONTROLLER
  ===============================================
  
  This ESP32 acts as the client controller for the Smart Cabinet system.
  It handles:
  - Motion detection and user interaction
  - Stepper motor control for door/drawer operations
  - Relay control for solenoids and LED strips
  - Safety switches (limit switches, reed switch)
  - ESP-NOW communication with the host controller
  
  Components managed:
  - PIR Motion Sensor
  - TB6600 Stepper Motor Drivers (x2)
  - 4-Channel Relay Module
  - Limit Switches (safety/homing)
  - Reed Switch (door position)
  - ESP-NOW Client
  
  Author: QPPD
  Version: 2.0
  Date: 2025
*/

#include <WiFi.h>
#include "client_pins.h"
#include "MotionSensor.h"
#include "TB6600.h" 
#include "Relay4.h"
#include "LimitSwitch.h"
#include "ReedSwitch.h"
#include "ESPNowClient.h"

// ===========================================
// HOST ESP32 MAC ADDRESS - REPLACE WITH YOUR HOST'S MAC ADDRESS
// ===========================================
uint8_t hostMAC[] = {0xFF, 0xFF, 0xFF, 0xFF, 0xFF, 0xFF};

// ===========================================
// COMPONENT INSTANCES
// ===========================================

// Motion detection
MotionSensor motionSensor(CLIENT_PIR_PIN);

// Motor controllers
TB6600 doorMotor(CLIENT_TB1_DIR, CLIENT_TB1_STEP, CLIENT_TB1_ENABLE);
TB6600 lockMotor(CLIENT_TB2_DIR, CLIENT_TB2_STEP, CLIENT_TB2_ENABLE);

// Relay control (only relay 1 on pin 13)
Relay4 relayBoard(13, CLIENT_RELAY2_PIN, CLIENT_RELAY3_PIN, CLIENT_RELAY4_PIN);

// Safety switches (only one limit switch on pin 5)
LimitSwitch limitSwitch(5);
ReedSwitch reedSwitch(CLIENT_REED_SWITCH_PIN);

// ESP-NOW communication
ESPNowClient espNowClient;

// ===========================================
// SYSTEM STATE VARIABLES
// ===========================================

enum ClientState {
  CLIENT_IDLE,
  CLIENT_OPENING,
  CLIENT_OPEN,
  CLIENT_CLOSING,
  CLIENT_LOCKED,
  CLIENT_ERROR
};

ClientState currentState = CLIENT_IDLE;
ClientState previousState = CLIENT_IDLE;

// Timing variables
unsigned long lastMotionTime = 0;
unsigned long lastStatusUpdate = 0;
unsigned long motorStartTime = 0;
unsigned long lastWifiCheck = 0;

// Flags
bool doorIsOpen = false;
bool lockEngaged = true;
bool motionDetected = false;
bool emergencyStop = false;
bool systemEnabled = true;

// Motor operation flags
bool doorMotorRunning = false;
bool lockMotorRunning = false;

// ===========================================
// CALLBACK FUNCTIONS
// ===========================================

void onMotionDetected(bool motion) {
  motionDetected = motion;
  if (motion) {
    lastMotionTime = millis();
    Serial.println("[CLIENT] Motion detected!");
    
    // Send motion event to host via ESP-NOW
    espNowClient.sendMotionDetected(true);
  }
}

// ===========================================
// INITIALIZATION
// ===========================================

void setup() {
  Serial.begin(115200);
  delay(2000);
  
  Serial.println("===============================================");
  Serial.println("SMART CABINET CLIENT CONTROLLER STARTING...");
  Serial.println("===============================================");
  
  // Initialize hardware components
  initializeHardware();
  
  // Initialize ESP-NOW communication
  initializeESPNow();
  
  Serial.println("[CLIENT] System initialization complete!");
  Serial.println("===============================================");
  
  // Print test commands help
  Serial.println();
  printTestHelp();
  
  // Initial state
  currentState = CLIENT_LOCKED;
  sendStatusUpdate();
}

// ===========================================
// MAIN LOOP
// ===========================================

void loop() {
  // Handle serial commands for testing
  handleSerialCommands();
  
  // Update all sensors and components
  updateComponents();
  
  // Handle state machine
  handleStateMachine();
  
  // Handle emergency conditions
  handleEmergencyConditions();
  
  // Maintain network connection
  maintainConnections();
  
  // Send periodic status updates
  sendPeriodicUpdates();
  
  // Small delay to prevent overwhelming the system
  delay(10);
}

// ===========================================
// INITIALIZATION FUNCTIONS
// ===========================================

void initializeESPNow() {
  Serial.println("[CLIENT] Initializing ESP-NOW...");
  
  espNowClient.begin();
  espNowClient.setPeerAddress(hostMAC);
  espNowClient.setMessageCallback(onESPNowMessage);
  
  Serial.println("[CLIENT] ESP-NOW initialized and paired with host");
}

void initializeHardware() {
  Serial.println("[CLIENT] Initializing hardware components...");
  
  // Initialize motion sensor
  motionSensor.begin();
  motionSensor.setCallback(onMotionDetected);
  Serial.println("[CLIENT] Motion sensor initialized");
  
  // Initialize motors
  doorMotor.begin();
  lockMotor.begin();
  doorMotor.enable(false); // Start disabled
  lockMotor.enable(false); // Start disabled  
  Serial.println("[CLIENT] Stepper motors initialized");
  
  // Initialize relay board
  relayBoard.begin();
  relayBoard.allOff(); // Start with all relays off
  Serial.println("[CLIENT] Relay board initialized");
  
  // Initialize switches
  limitSwitch.begin();
  reedSwitch.begin();
  Serial.println("[CLIENT] Safety switches initialized");
  
  // Check initial door state
  doorIsOpen = !reedSwitch.isClosed();
  Serial.print("[CLIENT] Initial door state: ");
  Serial.println(doorIsOpen ? "OPEN" : "CLOSED");
}

// ESP-NOW message handler
void onESPNowMessage(const char* command, int userId, bool success, const char* data) {
  Serial.print("[CLIENT] ESP-NOW Command: ");
  Serial.print(command);
  Serial.print(" | UserID: ");
  Serial.println(userId);
  
  if (strcmp(command, "unlock") == 0 && success) {
    // Received unlock command from host
    Serial.println("[CLIENT] Unlock command received, opening cabinet...");
    unlockAndOpen(); // Use state machine instead of blocking executeUnlock()
  } else if (strcmp(command, "authResult") == 0) {
    // Received authentication result
    if (success) {
      Serial.println("[CLIENT] Authentication successful");
    } else {
      Serial.println("[CLIENT] Authentication failed");
    }
  }
}

// ===========================================
// COMPONENT UPDATE FUNCTIONS  
// ===========================================

void updateComponents() {
  // Update all sensors and components
  motionSensor.update();
  doorMotor.update();
  lockMotor.update();
  limitSwitch.update();
  
  // Check motor completion status
  checkMotorCompletion();
}

void checkMotorCompletion() {
  // Check if door motor finished
  if (doorMotorRunning && !doorMotor.isBusy()) {
    doorMotorRunning = false;
    doorMotor.enable(false);
    Serial.println("[CLIENT] Door motor operation completed");
    
    // Update door state based on operation
    doorIsOpen = !reedSwitch.isClosed();
  }
  
  // Check if lock motor finished  
  if (lockMotorRunning && !lockMotor.isBusy()) {
    lockMotorRunning = false;
    lockMotor.enable(false);
    Serial.println("[CLIENT] Lock motor operation completed");
    
    // Update lock state
  }
}

// ===========================================
// STATE MACHINE
// ===========================================

void handleStateMachine() {
  switch (currentState) {
    case CLIENT_IDLE:
      handleIdleState();
      break;
      
    case CLIENT_OPENING:
      handleOpeningState();
      break;
      
    case CLIENT_OPEN:
      handleOpenState();
      break;
      
    case CLIENT_CLOSING:
      handleClosingState();
      break;
      
    case CLIENT_LOCKED:
      handleLockedState();
      break;
      
    case CLIENT_ERROR:
      handleErrorState();
      break;
  }
  
  // Send state change notifications
  if (currentState != previousState) {
    Serial.print("[CLIENT] State changed: ");
    Serial.print(stateToString(previousState));
    Serial.print(" -> ");
    Serial.println(stateToString(currentState));
    
    sendStatusUpdate();
    previousState = currentState;
  }
}

void handleIdleState() {
  // Waiting for authentication signal from host
  // Motion detection is active but no action taken until authorized
}

void handleOpeningState() {
  if (!doorMotorRunning) {
    // Start door opening sequence
    Serial.println("[CLIENT] Starting door opening sequence...");
    Serial.print("[CLIENT] Will open door for ");
    Serial.print(CLIENT_DOOR_OPEN_STEPS);
    Serial.println(" steps");
    
    // Release solenoid lock first
    relayBoard.set(1, true); // Energize solenoid to release lock
    delay(500); // Give solenoid time to actuate
    
    // Disengage mechanical lock (blocking)
    if (lockEngaged) {
      Serial.println("[CLIENT] Releasing lock...");
      lockMotor.enable(true);
      lockMotor.setDirection(false); // Direction for unlocking
      lockMotor.stepMany(CLIENT_LOCK_RELEASE_STEPS, CLIENT_MOTOR_PULSE_US, CLIENT_MOTOR_GAP_US);
      lockMotor.enable(false);
      lockEngaged = false;
      Serial.println("[CLIENT] Lock released");
    }
    
    // Open door (blocking with watchdog feeding)
    Serial.println("[CLIENT] Opening door...");
    doorMotor.enable(true);
    doorMotor.setDirection(false); // Direction for opening
    
    // Use manual stepping with watchdog feeding for long movements
    unsigned long stepCount = 0;
    unsigned long targetSteps = CLIENT_DOOR_OPEN_STEPS;
    
    while (stepCount < targetSteps) {
      doorMotor.stepOnce(CLIENT_MOTOR_PULSE_US);
      delayMicroseconds(CLIENT_MOTOR_GAP_US);
      stepCount++;
      
      // Feed watchdog and print progress every 2000 steps
      if (stepCount % 2000 == 0) {
        yield(); // Feed the watchdog
        Serial.print("[CLIENT] Opening... ");
        Serial.print(stepCount);
        Serial.print("/");
        Serial.print(targetSteps);
        Serial.print(" (");
        Serial.print((stepCount * 100) / targetSteps);
        Serial.println("%)");
      }
    }
    
    doorMotor.enable(false);
    doorIsOpen = true;
    Serial.println("[CLIENT] Door fully opened!");
    
    // Turn on LED strip
    relayBoard.set(2, true);
    
    // Move to open state
    currentState = CLIENT_OPEN;
    lastMotionTime = millis(); // Reset motion timer
  }
}

void handleOpenState() {
  // Door is open, monitor for motion and auto-close timer
  
  // Check for auto-close condition (no motion for specified time)
  if (millis() - lastMotionTime > CLIENT_MOTION_TIMEOUT) {
    Serial.println("[CLIENT] Auto-close triggered - no motion detected");
    currentState = CLIENT_CLOSING;
  }
}

void handleClosingState() {
  if (!doorMotorRunning) {
    Serial.println("[CLIENT] Starting door closing sequence...");
    Serial.println("[CLIENT] Will close until limit switch is pressed");
    
    // Turn off LED strip
    relayBoard.set(2, false);
    
    // Close door until limit switch is triggered (blocking with watchdog feeding)
    Serial.println("[CLIENT] Closing door...");
    doorMotor.enable(true);
    doorMotor.setDirection(true); // Direction for closing
    
    unsigned long stepCount = 0;
    unsigned long startTime = millis();
    unsigned long maxTime = 60000; // 60 second timeout
    bool limitPressed = false;
    
    while (!limitPressed && (millis() - startTime < maxTime)) {
      // Check limit switch
      limitSwitch.update();
      if (limitSwitch.isPressed()) {
        limitPressed = true;
        Serial.println("[CLIENT] Limit switch pressed!");
        break;
      }
      
      // Step the motor
      doorMotor.stepOnce(CLIENT_MOTOR_PULSE_US);
      delayMicroseconds(CLIENT_MOTOR_GAP_US);
      stepCount++;
      
      // Feed watchdog and print status every 2000 steps
      if (stepCount % 2000 == 0) {
        yield(); // Feed the watchdog
        Serial.print("[CLIENT] Closing... Steps: ");
        Serial.print(stepCount);
        Serial.print(" | Time: ");
        Serial.print((millis() - startTime) / 1000);
        Serial.println("s");
      }
    }
    
    doorMotor.enable(false);
    doorIsOpen = false;
    
    Serial.print("[CLIENT] Door closed after ");
    Serial.print(stepCount);
    Serial.println(" steps");
    
    if (!limitPressed) {
      Serial.println("[CLIENT] WARNING: Limit switch not pressed (timeout)");
    }
    
    // Small delay before engaging lock
    delay(500);
    
    // Engage mechanical lock (blocking)
    Serial.println("[CLIENT] Engaging lock...");
    lockMotor.enable(true);
    lockMotor.setDirection(true); // Direction for locking  
    lockMotor.stepMany(CLIENT_LOCK_ENGAGE_STEPS, CLIENT_MOTOR_PULSE_US, CLIENT_MOTOR_GAP_US);
    lockMotor.enable(false);
    lockEngaged = true;
    Serial.println("[CLIENT] Lock engaged");
    
    // Engage solenoid lock
    relayBoard.set(1, false); // De-energize solenoid to engage lock
    
    // Move to locked state
    currentState = CLIENT_LOCKED;
    Serial.println("[CLIENT] Cabinet fully locked!");
  }
}

void handleLockedState() {
  // Door is locked, system is secure
  // Wait for unlock command from host
}

void handleErrorState() {
  // Stop all operations
  stopAllMotors();
  relayBoard.allOff();
  
  // LED flashing disabled to prevent relay clicking
  // Uncomment to enable visual error indication
  /*
  static unsigned long lastFlash = 0;
  static bool ledState = false;
  
  if (millis() - lastFlash > 500) {
    ledState = !ledState;
    relayBoard.set(2, ledState);
    lastFlash = millis();
  }
  */
}

// ===========================================
// MOTOR CONTROL FUNCTIONS
// ===========================================

void stopAllMotors() {
  Serial.println("[CLIENT] EMERGENCY STOP - All motors stopped!");
  
  doorMotor.emergencyStop();
  lockMotor.emergencyStop();
  doorMotorRunning = false;
  lockMotorRunning = false;
  
  // Send emergency stop notification via ESP-NOW
  espNowClient.sendStatus("emergency_stop");
}

// ===========================================
// EMERGENCY HANDLING
// ===========================================

void handleEmergencyConditions() {
  // Check for emergency stop conditions
  if (emergencyStop) {
    currentState = CLIENT_ERROR;
    return;
  }
  
  // Check motor timeouts
  if ((doorMotorRunning || lockMotorRunning) && 
      (millis() - motorStartTime > CLIENT_MOTOR_TIMEOUT)) {
    Serial.println("[CLIENT] Motor operation timeout!");
    emergencyStop = true;
    return;
  }
}

// ===========================================
// NETWORK COMMUNICATION
// ===========================================

void maintainConnections() {
  // ESP-NOW doesn't require connection maintenance
}

void sendPeriodicUpdates() {
  if (millis() - lastStatusUpdate > CLIENT_STATUS_UPDATE_INTERVAL) {
    sendStatusUpdate();
    lastStatusUpdate = millis();
  }
}

void sendStatusUpdate() {
  // Send status update via ESP-NOW
  char statusStr[50];
  sprintf(statusStr, "%s|door:%d|lock:%d", 
          stateToString(currentState),
          doorIsOpen ? 1 : 0,
          lockEngaged ? 1 : 0);
  espNowClient.sendStatus(statusStr);
  
  // Also send door state
  espNowClient.sendDoorState(doorIsOpen);
}

// ===========================================
// UTILITY FUNCTIONS
// ===========================================

String stateToString(ClientState state) {
  switch (state) {
    case CLIENT_IDLE: return "IDLE";
    case CLIENT_OPENING: return "OPENING";
    case CLIENT_OPEN: return "OPEN";
    case CLIENT_CLOSING: return "CLOSING";
    case CLIENT_LOCKED: return "LOCKED";
    case CLIENT_ERROR: return "ERROR";
    default: return "UNKNOWN";
  }
}

// ===========================================
// PUBLIC API FUNCTIONS
// ===========================================

void unlockAndOpen() {
  if (currentState == CLIENT_LOCKED && !emergencyStop) {
    Serial.println("[CLIENT] Unlock and open command received");
    currentState = CLIENT_OPENING;
  }
}

void forceClose() {
  if (currentState == CLIENT_OPEN && !emergencyStop) {
    Serial.println("[CLIENT] Force close command received");  
    currentState = CLIENT_CLOSING;
  }
}

void clearEmergencyStop() {
  if (currentState == CLIENT_ERROR) {
    Serial.println("[CLIENT] Emergency stop cleared");
    emergencyStop = false;
    currentState = CLIENT_IDLE;
  }
}

void enableSystem(bool enable) {
  systemEnabled = enable;
  Serial.print("[CLIENT] System ");
  Serial.println(enable ? "ENABLED" : "DISABLED");
}

// ===========================================
// SERIAL COMMAND TESTING FUNCTIONS
// ===========================================

void handleSerialCommands() {
  if (Serial.available() > 0) {
    String command = Serial.readStringUntil('\n');
    command.trim();
    command.toLowerCase();
    
    Serial.println();
    Serial.println("========================================");
    Serial.print("[TEST] Command received: ");
    Serial.println(command);
    Serial.println("========================================");
    
    if (command == "test_relay") {
      testRelay();
    } else if (command == "test_motor1") {
      testMotor(1);
    } else if (command == "test_motor2") {
      testMotor(2);
    } else if (command == "test_limit") {
      testLimitSwitch();
    } else if (command == "test_motor_limit") {
      testMotorWithLimitSwitch();
    } else if (command == "test_close_door") {
      testCloseDoor();
    } else if (command == "test_open_door") {
      testOpenDoor();
    } else if (command == "test_motion") {
      testMotionSensor();
    } else if (command == "test_reed") {
      testReedSwitch();
    } else if (command == "help") {
      printTestHelp();
    } else if (command != "") {
      Serial.println("[TEST] Unknown command. Type 'help' for available commands.");
    }
  }
}

void printTestHelp() {
  Serial.println();
  Serial.println("╔════════════════════════════════════════════════════════════╗");
  Serial.println("║          SMART CABINET TEST COMMANDS                       ║");
  Serial.println("╚════════════════════════════════════════════════════════════╝");
  Serial.println();
  Serial.println("Available test commands:");
  Serial.println("  test_relay       - Test relay 1 (Pin 13) - ON/OFF sequence");
  Serial.println("  test_motor1      - Test Motor 1 (Door Motor) - 2s CW, 2s CCW");
  Serial.println("  test_motor2      - Test Motor 2 (Lock Motor) - 2s CW, 2s CCW");
  Serial.println("  test_limit       - Test limit switch (Pin 5) - press 3x to pass");
  Serial.println("  test_motor_limit - Motor 1 runs until limit switch pressed");
  Serial.println("  test_close_door  - Close door until limit switch is pressed");
  Serial.println("  test_open_door   - Open door for set steps (CLIENT_DOOR_OPEN_STEPS)");
  Serial.println("  test_motion      - Test motion sensor (trigger to pass)");
  Serial.println("  test_reed        - Test reed switch (trigger to pass)");
  Serial.println("  help             - Show this help message");
  Serial.println();
  Serial.println("════════════════════════════════════════════════════════════");
  Serial.println();
}

void testRelay() {
  Serial.println();
  Serial.println("┌────────────────────────────────────────┐");
  Serial.println("│      RELAY TEST STARTED                │");
  Serial.println("└────────────────────────────────────────┘");
  Serial.println();
  
  Serial.println("[TEST] Testing Relay 1 (Pin 13)...");
  
  // Turn ON
  Serial.println("  → Turning relay ON");
  relayBoard.set(1, true);
  delay(2000);
  
  // Turn OFF
  Serial.println("  → Turning relay OFF");
  relayBoard.set(1, false);
  delay(500);
  
  Serial.println("[TEST] Relay 1 test completed ");
  Serial.println();
  
  Serial.println("┌────────────────────────────────────────┐");
  Serial.println("│    RELAY TEST COMPLETED - SUCCESS     │");
  Serial.println("└────────────────────────────────────────┘");
  Serial.println();
}

void testMotor(int motorNum) {
  Serial.println();
  Serial.print("┌────────────────────────────────────────┐");
  Serial.println();
  Serial.print("│      MOTOR ");
  Serial.print(motorNum);
  Serial.println(" TEST STARTED              │");
  Serial.println("└────────────────────────────────────────┘");
  Serial.println();
  
  TB6600* motor = (motorNum == 1) ? &doorMotor : &lockMotor;
  String motorName = (motorNum == 1) ? "Door Motor" : "Lock Motor";
  
  Serial.print("[TEST] Testing ");
  Serial.println(motorName);
  Serial.println();
  
  // Enable motor
  motor->enable(true);
  Serial.println("[TEST] Motor enabled");
  
  // Test CW direction
  Serial.println("[TEST] Running Clockwise for 2 seconds...");
  motor->setDirection(true);
  unsigned long startTime = millis();
  while (millis() - startTime < 2000) {
    motor->stepOnce(CLIENT_MOTOR_PULSE_US);
    delayMicroseconds(CLIENT_MOTOR_GAP_US);
  }
  Serial.println("[TEST] Clockwise rotation completed ");
  delay(500);
  
  // Test CCW direction
  Serial.println("[TEST] Running Counter-Clockwise for 2 seconds...");
  motor->setDirection(false);
  startTime = millis();
  while (millis() - startTime < 2000) {
    motor->stepOnce(CLIENT_MOTOR_PULSE_US);
    delayMicroseconds(CLIENT_MOTOR_GAP_US);
  }
  Serial.println("[TEST] Counter-Clockwise rotation completed ");
  
  // Disable motor
  motor->enable(false);
  Serial.println("[TEST] Motor disabled");
  Serial.println();
  
  Serial.print("┌────────────────────────────────────────┐");
  Serial.println();
  Serial.print("│   MOTOR ");
  Serial.print(motorNum);
  Serial.println(" TEST COMPLETED - SUCCESS  │");
  Serial.println("└────────────────────────────────────────┘");
  Serial.println();
}
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

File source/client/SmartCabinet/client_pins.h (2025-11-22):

#ifndef SMART_CABINET_CLIENT_PINS_H
#define SMART_CABINET_CLIENT_PINS_H

// ===========================================
// CLIENT DEVICE PIN CONFIGURATION
// ===========================================
// This configuration is for the client ESP32 that handles:
// - Motion detection and user interface
// - Motor control and mechanical operations
// - Relay control for actuators
// - Safety switches and sensors
// - ESP-NOW communication with host
//
// NOTES ON PIN SELECTION:
// - Avoided GPIO 0, 2, 5, 12, 15 (strapping pins - can cause boot issues)
// - GPIO 6-11 are flash pins (NEVER USE)
// - GPIO 34-39 are input-only (OK for sensors)
// - Safe pins: 4, 13, 14, 16, 17, 18, 19, 21, 22, 23, 25, 26, 27, 32, 33

// PIR Motion Sensor
static const uint8_t CLIENT_PIR_PIN = 19; // Input-only pin - OK for sensor

// TB6600 Stepper Motor Driver #1 (Door/Drawer Motor)
static const uint8_t CLIENT_TB1_DIR = 25;     // Direction pin (safe pin)
static const uint8_t CLIENT_TB1_STEP = 26;    // Step pulse pin (safe pin)
static const uint8_t CLIENT_TB1_ENABLE = 27;  // Enable pin (LOW = enabled)

// TB6600 Stepper Motor Driver #2 (Lock/Mechanism Motor)  
static const uint8_t CLIENT_TB2_DIR = 32;     // Direction pin (safe pin)
static const uint8_t CLIENT_TB2_STEP = 33;    // Step pulse pin (safe pin)
static const uint8_t CLIENT_TB2_ENABLE = 39;  // Enable pin (LOW = enabled)

// 4-Channel Relay Module (Controls solenoids, LED strips, etc.)
static const uint8_t CLIENT_RELAY1_PIN = 34;  // Solenoid lock control
static const uint8_t CLIENT_RELAY2_PIN = 13;  // LED strip power
static const uint8_t CLIENT_RELAY3_PIN = 22;  // Auxiliary device 1
static const uint8_t CLIENT_RELAY4_PIN = 23;  // Auxiliary device 2

// Limit Switches (Safety/Homing)
static const uint8_t CLIENT_LIMIT_MIN_PIN = 5;  // Minimum position limit switch - Input-only, OK
static const uint8_t CLIENT_LIMIT_MAX_PIN = 36;  // Maximum position limit switch - Input-only, OK

// Reed Switch (Door closed detection)
static const uint8_t CLIENT_REED_SWITCH_PIN = 18;  // Reed switch - Input-only, OK

// Timing Constants
static const unsigned long CLIENT_MOTION_TIMEOUT = 60000;      // 60 seconds no motion = auto-close
static const unsigned long CLIENT_MOTOR_TIMEOUT = 30000;       // 30 seconds max motor operation
static const unsigned long CLIENT_STATUS_UPDATE_INTERVAL = 1000; // Send status every second

// Motor Configuration
// NEMA23 Stepper Motor: 3.0A, 1.8°/step (200 steps/revolution)
// 1 full rotation = 200 steps
// With 1/8 microstepping on TB6600 = 1600 steps/revolution
static const unsigned long CLIENT_DOOR_OPEN_STEPS = 52000;     // Steps to fully open door (adjust based on your cabinet)
static const unsigned long CLIENT_DOOR_CLOSE_STEPS = 60000;    // Max steps for closing (will stop at limit switch)
static const unsigned long CLIENT_LOCK_ENGAGE_STEPS = 400;     // Steps to engage lock
static const unsigned long CLIENT_LOCK_RELEASE_STEPS = 400;    // Steps to release lock

// Motor Speed Settings (microseconds)
// NEMA23 3.0A motor can handle faster speeds than smaller motors
static const unsigned int CLIENT_MOTOR_PULSE_US = 50;          // Pulse width (min ~5us for TB6600)
static const unsigned int CLIENT_MOTOR_GAP_US = 500;           // Gap between pulses (faster = lower value)

#endif // SMART_CABINET_CLIENT_PINS_H

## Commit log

2025-10-24 Updated pin configuration of host
2025-10-24 v2.0: Replace RTC with NTP, add fingerprint management, improve buzzer system, integrate WiFi - WebSocket under development
    [SmartCabinet.ino]
2025-10-24 Fix ESP-NOW callback signature for ESP32 Core 3.1.2 and optimize LCD display
    [SmartCabinet.ino]
2025-10-24 Add tactile button and fingerprint enrollment trigger to host controller
2025-10-24 Add fingerprint enrollment system and fix authentication flow
    - Added TactileButton class for debounced button handling
    - Implemented one-touch enrollment via GPIO 23 button
    - Fixed authentication double-read issue (removed isFingerDetected pre-check)
    - Added error code differentiation (-1: no finger, -2: wrong finger)
    - Auto ID assignment based on template count
    - LCD enrollment wizard with step-by-step instructions
    - Database capacity checking (max 50 users)
    - Updated README with enrollment guide and ESP-NOW documentation
    - Authentication now working reliably with enrolled fingerprints
    [SmartCabinet.ino]
2025-10-24 Reduce buzzer noise - single beeps only
    - Reduced all authentication beeps to 1 beep (success/fail)
    - Reduced enrollment beeps to 1 beep (success/fail)
    - Faster setup: reduced delays from 1000ms to 500ms
    - Shorter initial beep (100ms to 50ms)
    - Single welcome beep instead of sequence
    - Quieter and faster startup
    [SmartCabinet.ino]
2025-10-31 Updated scanner case
    [Cabiner_Scanner_Case.stl, Cabinet_Scanner_Case.stl]
2025-10-31 Updated scanner case and mount models
    [Cabinet_Scanner_Case_Mount.stl]
2025-11-12 Update: Limit switch moved to pin 5, updated docs and tests for reliability
2025-11-13 Added stepper mount model
2025-11-13 docs(models): update README to include new 3D model files (CE3V3SE_Cabinet_Stepper_Mount_And_Bearing_Mount.gcode) with descriptions in both Project Structure and 3D Printable Components sections. Als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
    [Cabinet_Actuator_Mount.stl]
2025-11-13 docs(readme): add image previews for 3D models in 3D Printable Components section
2025-11-13 docs(readme): add Cabinet Door Puller Mount model, fix 3D Printable Components section structure with proper image displays, and reorganize Project Structure section alphabetically
    [Cabinet_Door_Puller_Mount.stl]
2025-11-13 docs(readme): add CE3V3SE_Cabinet_Door_Puller_Mount.gcode to Door Puller Mount documentation in both 3D Printable Components and Project Structure sections
2025-11-13 docs(readme): add Client wiring diagram, fix scattered 3D model content by consolidating all model information in proper sections, clean up Table of Contents and Key Features sections
    [Client.fzz]
2025-11-14 Update README.md to include comprehensive documentation for newly added 3D models
    - Added detailed sections for Bearing Mount, Limit Switch Mount, and Stick Mount
    - Included image previews, file availability lists (.stl, .png, .gcode), purposes, and key features for each model
    - Updated project structure tree with new model files and descriptions
    - Maintained professional formatting and consistency with existing documentation
    - Enhanced project completeness by documenting all available 3D printable components
    [Cabinet_Bearing_Mount.stl, Cabinet_Limit_Switch_Mount.stl, Cabinet_Limit_Switch_Mount_Cover.stl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]
2025-11-14 Add documentation for Cabinet Scanner Case Cover 3D model
    - Added detailed section for Scanner Case Cover in 3D Printable Components
    - Included image preview, file availability (.stl, .png, .gcode), purpose, and features
    - Updated project structure tree with new cover files
    - Maintained consistent formatting and professional documentation style
    - Enhanced scanner enclosure protection documentation
    [Cabinet_Scanner_Case_Cover.stl]
2025-11-14 Update documentation for Cabinet Limit Switch Mount Cover
    - Separated Limit Switch Mount Cover into its own detailed section
    - Removed cover references from main Limit Switch Mount section
    - Added dedicated section with files, purpose, and features for the cover
    - Maintained consistent formatting and professional structure
    - Enhanced clarity by documenting cover as separate component
    [Cabinet_Limit_Switch_Mount_Cover.stl]
2025-11-15 Add documentation for Cabinet Motion Sensor Mount and Cover
    - Added detailed sections for Motion Sensor Mount and Motion Sensor Mount Cover
    - Included image preview for mount, file lists (.stl), purposes, and features for both
    - Updated project structure with new motion sensor mount files
    - Added missing .gcode file for Limit Switch Mount Cover
    - Maintained consistent professional formatting and structure
    - Enhanced documentation completeness for all 3D printable components
    [Cabinet_Motion_Sensor_Mount.stl, Cabinet_Motion_Sensor_Mount_Cover.stl]
2025-11-15 Add gcode file for Cabinet Motion Sensor Mount
    - Added CE3V3SE_Cabinet_Motion_Sensor_Mount.gcode to files available in README
    - Updated project structure to include the new gcode file
    - Maintained consistent documentation format
    - Enhanced printability with pre-sliced file for Creality Ender 3 V3 SE
2025-11-21 Remove internet dependency: Transition to fully offline ESP-NOW communication
    BREAKING CHANGES:
    - Removed all WiFi and internet connectivity requirements
    - System now operates completely offline using ESP-NOW peer-to-peer communication
    Host Controller Changes:
    - Removed NTPTime dependency and WiFi connection code
    - Replaced internet time display with system uptime counter
    - Faster boot time without WiFi connection delays
    - Removed WiFi credentials from pins.h configuration
    Client Controller Changes:
    - Removed WebSocketClient and replaced with ESPNowClient
    - Implemented ESP-NOW peer-to-peer communication protocol
    - Added onESPNowMessage callback handler for host commands
    - Added executeUnlo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
    [ESPNowClient.cpp, SmartCabinet.ino, client_pins.h]
2025-11-21 Fix compilation errors in client code
    - Changed lockMotor.step() to lockMotor.stepMany() (correct TB6600 method)
    - Changed doorMotor.step() to doorMotor.stepMany() (correct TB6600 method)
    - Removed remaining WebSocket code fragments from sendStatusUpdate()
    - Removed ArduinoJson references (doc, serializeJson)
    - Removed wsClient references that were missed in previous commit
    All compilation errors resolved. Client now properly uses TB6600 API and ESP-NOW only.
    [SmartCabinet.ino]
2025-11-21 feat: Invert motor directions and add comprehensive door testing
    - Invert motor directions for proper cabinet operation:
    * Fingerprint/user authentication now opens cabinet door (CCW direction)
    * test_motor_limit now closes cabinet door (CW direction)
    * Updated executeUnlock(), handleOpeningState(), and handleClosingState()
    - Add two new comprehensive test commands:
    * test_close_door: Closes door until limit switch is pressed (CW direction)
    * test_open_door: Opens door for CLIENT_DOOR_OPEN_STEPS (CCW direction)
    * Both tests include progress tracking, safety timeouts, and detailed feedback
    - Update help menu to include new test commands with clear descriptions
    This ensures prop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
    [SmartCabinet.ino]
2025-11-21 docs: Update README for November 2025 changes
    - Add November 2025 update section documenting motor direction inversion and new test commands
    - Document test_close_door and test_open_door commands with proper descriptions
    - Update Testing & Validation section with comprehensive serial command reference
    - Clarify motor directions: CCW for opening, CW for closing
    - Maintain version 2.0 for significant feature updates
2025-11-22 Fix door motor control with watchdog feeding and limit switch-based closing
    Major Changes:
    - Replaced non-blocking motor control (startSteps) with blocking motor control (stepMany) in state machine to ensure complete execution
    - Added yield() calls every 2000 steps to feed ESP32 watchdog timer, preventing resets during long motor operations (52000+ steps)
    - Changed door closing logic from fixed steps to limit switch detection - door closes until limit switch is pressed
    - Updated CLIENT_DOOR_OPEN_STEPS from 2000 to 52000 steps for full cabinet door opening
    - Updated CLIENT_DOOR_CLOSE_STEPS from 2000 to 60000 (max safety value, actual closing stops at limit switch)
    Technical Details:
    - handle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
    [SmartCabinet.ino, client_pins.h]
2025-11-22 Fix fingerprint enrollment ID management - prevent overwriting existing fingerprints
    Problem:
    - All new fingerprint enrollments were using ID #1, overwriting previous fingerprints
    - templateCount + 1 approach didn't handle ID gaps from deleted fingerprints
    - Only one fingerprint could be registered at a time
    Solution:
    - Added getNextAvailableID() function that scans all IDs from 1 to MAX_ENROLLED_FINGERPRINTS
    - Finds first empty slot by checking each ID with loadModel()
    - Properly handles ID gaps when fingerprints are deleted
    - Added loadModel(uint16_t id) method to FingerprintAS608 class
    Changes:
    - SmartCabinet.ino: Added getNextAvailableID() helper function
    - SmartCabinet.ino: Changed en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
    [SmartCabinet.ino]
2025-11-22 Fix motor not operating when triggered by fingerprint authentication
    - Motor worked correctly with test_open_door command
    - Motor did not operate when unlocking via fingerprint authentication
    - ESP-NOW unlock callback was using old executeUnlock() function with blocking stepMany() without watchdog feeding
    Root Cause:
    - Two different unlock functions existed:
    1. executeUnlock() - Old blocking version without watchdog feeding (used by ESP-NOW)
    2. unlockAndOpen() + state machine - New version with watchdog feeding (used by tests)
    - ESP-NOW callback called executeUnlock() which didn't have yield() calls for watchdog
    - This caused ESP32 reset during 52000 step motor operation when t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
    [SmartCabinet.ino]
2025-11-22 Fix limit switch blocking motor operation when door is closed at rest
    - Limit switch callback (onLimitSwitchTriggered) set emergencyStop=true whenever limit switch was pressed
    - When cabinet door is closed at rest, limit switch is pressed (normal state)
    - emergencyStop flag prevented unlockAndOpen() from working
    - Motor wouldn't operate when fingerprint was granted because emergencyStop was true
    - Limit switch callback triggered emergency stop even when system is idle
    - Emergency stop should ONLY trigger during closing operation, not at rest
    - The callback was checking limit switch in every loop, blocking all motor operations
    - Removed onLimitSwitchTriggered(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
    [SmartCabinet.ino]
2025-11-26 Add 3D model visualization section with full assembly views to README
    - Added new '3D Model Visualizations' section showcasing complete assembly
    - Included SmartCabinetFullView.png (wireframe) and SmartCabinetFullViewRendered.png (rendered)
    - Added comprehensive description of assembly components and design features
    - Documented all mounting brackets, enclosures, and mechanical systems
    - Enhanced project documentation with visual representations of the physical design
    - Positioned section after 3D Printed Enclosures for logical documentation flow
    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
2025-11-26 Consolidate all Markdown files into single comprehensive README.md
    - Merged content from source/client/SmartCabinet/README.md and source/host/SmartCabinet/README.md into root README.md
    - Added comprehensive Maintenance section with regular checks, fingerprint sensor care, motor maintenance, and software updates
    - Added detailed Fingerprint Management section covering enrollment, template management, and best practices
    - Added Security Considerations section covering authentication, physical, and network security
    - Added Development and Customization section with guidelines for adding features, hardware modifications, and performance tuning
    - Removed outdated WebSocket references (replaced wi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
2025-12-21 Remove gcode and stl files from tracking and add to gitignore
2026-03-13 Fix header guard macro name in Relay4.h
